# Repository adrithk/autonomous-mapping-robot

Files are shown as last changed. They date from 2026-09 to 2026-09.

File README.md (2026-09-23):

# Autonomous Indoor Mapping Robot

**ROS 2 Jazzy • SLAM Toolbox • Nav2 • ros2_control • Gazebo • ESP32**

A custom differential-drive robot that builds maps of indoor rooms and navigates to destinations selected in RViz. Built around a 3D-printed chassis, Raspberry Pi 5 and 360-degree LiDAR, it connects embedded wheel-speed control with a complete ROS 2 mapping and navigation stack.

Mapping uses keyboard teleoperation with **SLAM Toolbox**. Once the map is saved, **AMCL** localizes the robot and **Nav2** plans and drives the route to each selected goal.

## Demo

### Real-room mapping

| Physical robot | Room map in RViz |
|:---:|:---:|
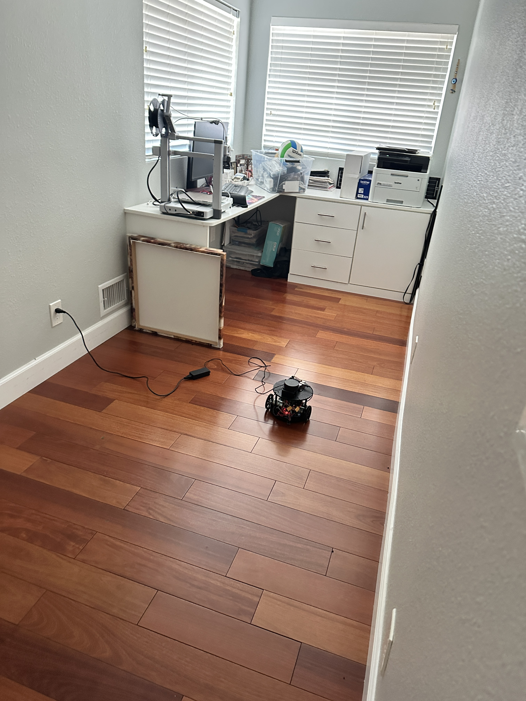
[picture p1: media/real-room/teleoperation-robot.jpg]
Custom robot with mounted LiDAR during room mapping
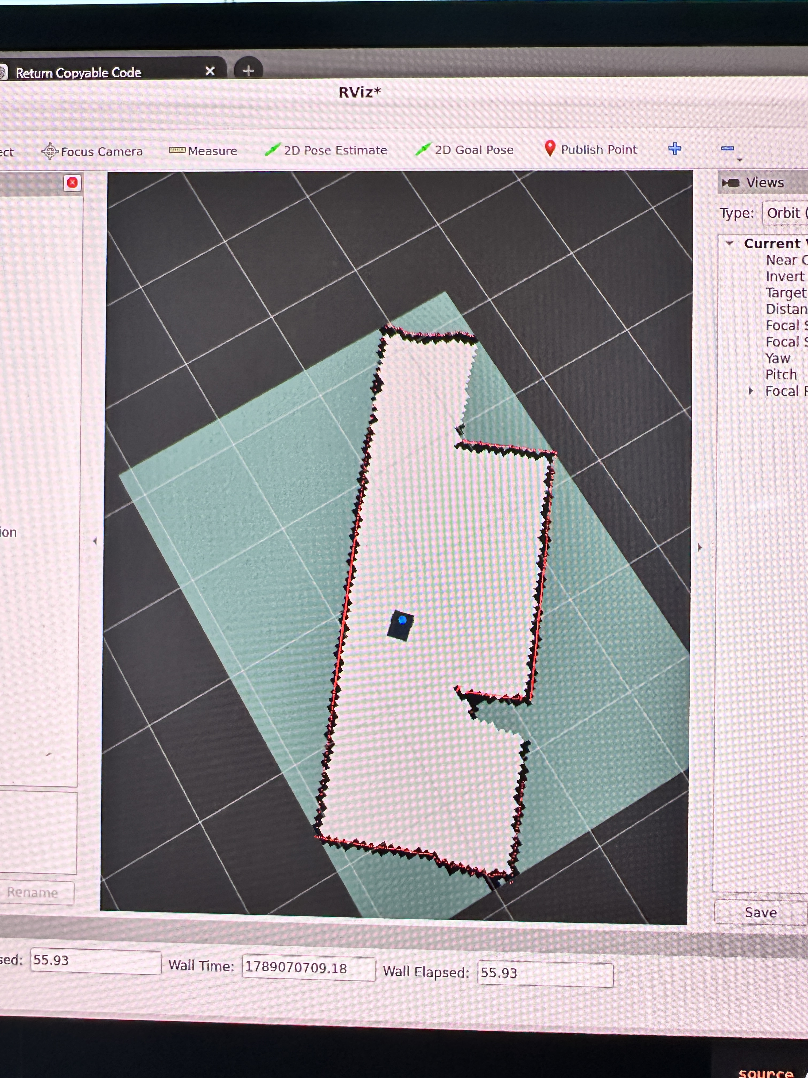
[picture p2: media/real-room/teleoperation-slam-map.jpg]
Room occupancy map and LiDAR returns displayed in RViz
|  |  |

The robot was driven through the room while LiDAR scans and encoder-based odometry supplied SLAM Toolbox with observations. The resulting occupancy map was saved for navigation.

### Nav2 navigation on the saved map

| Robot navigating · 49 s | RViz navigation view · 51 s |
|:---:|:---:|
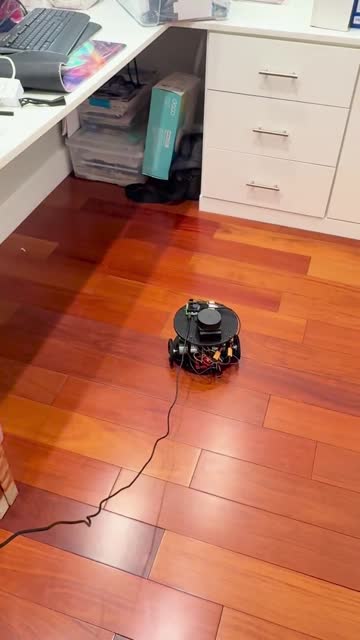
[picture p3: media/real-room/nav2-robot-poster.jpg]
Watch the physical navigation recording
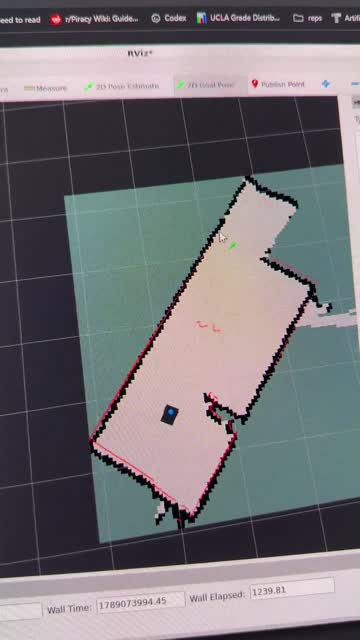
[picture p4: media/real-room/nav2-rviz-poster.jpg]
Watch the RViz navigation recording
|  |  |

Click a preview to watch or download the full-speed recording. On GitHub, use **View raw / Download** if playback is unavailable.

These initial demonstrations use operator-selected goals and tethered power. Setup, observations and measurement limits are documented in the [September 10 demonstration record](results/2026-09-10-real-room-mapping-navigation.md).

## Engineering highlights

- **Custom ROS hardware interface:** a C++ `ros2_control` plugin connects the standard differential-drive controller to the ESP32. The versioned serial protocol carries wheel commands and encoder feedback, with CRC checks, sequence tracking and an acknowledged stop at startup.
- **Embedded feedback control:** shared 50 Hz feed-forward/PI wheel controllers handle encoder sampling, command ramps and bounded motor outputs. An independent 250 ms watchdog stops commands that expire.
- **Mapping and navigation integration:** robot-specific Xacro, launch files, controller settings and TF connect wheel odometry and LiDAR to SLAM Toolbox, AMCL and Nav2.
- **Simulation and mechanical design:** Gazebo Harmonic provides a differential-drive model, simulated LiDAR and an obstacle room for integration testing. [STEP and STL files](hardware/cad/README.md) include the chassis, caster mount and LiDAR holder.

## How it works

The Raspberry Pi handles perception, localization and route planning. The ESP32 handles motor outputs and wheel-speed control, keeping command-loss handling independent of the ROS computer.

```text
Mapping:     LiDAR + wheel odometry → SLAM Toolbox → Saved map
Navigation:  Saved map + LiDAR + wheel odometry → AMCL localization

RViz goal → Nav2 → diff_drive_controller → Custom ros2_control plugin
                                                      │ USB serial
                                                      ▼
                                                ESP32 wheel PI → Motors
                                                      ▲
                                                   Encoders
```

### SLAM: turning laser scans into a room map

**Simultaneous Localization and Mapping (SLAM)** solves two connected problems: building a map of an unfamiliar space and estimating the robot's position within it. The RPLIDAR supplies a 360-degree slice of surrounding surfaces, while wheel encoders estimate how far the robot has moved between scans.

[SLAM Toolbox](https://github.com/SteveMacenski/slam_toolbox/tree/jazzy) uses **scan matching** to align overlapping laser observations and refine that motion estimate. It links successive robot poses into a **pose graph**. When a previously visited area is recognized, **loop closure** adds a constraint that lets the optimizer correct accumulated drift across the trajectory. The included [SLAM configuration](ros_ws/src/my_bot/config/slam.yaml) enables scan matching and loop closure with a Ceres solver.

The output is an **occupancy grid**: a spatial representation of free, occupied and unobserved areas. This project uses 5 cm map cells, displays the map and live laser returns in RViz, and exports the occupancy image with its scale and origin in a YAML file. Mapping is teleoperated; the saved map becomes the reference for autonomous navigation.

### Nav2: turning a destination into motion

For the physical saved-map workflow, **Adaptive Monte Carlo Localization (AMCL)** estimates the robot's position and heading. Its particle filter maintains candidate poses, predicts their movement from odometry, and weighs them against how well the current laser scan agrees with the map. This keeps navigation tied to observations of the room as the wheels turn. [AMCL documentation](https://docs.nav2.org/jazzy/configuration_and_development/configuration_guide/others/configuring_amcl/).

The operator then selects a destination and final heading in RViz. Nav2 separates finding a route from deciding how to drive the next part of it. The repository's [simulation navigation configuration](ros_ws/src/my_bot/config/nav2.yaml) makes that pipeline explicit:

- **Global planning:** NavFn uses Dijkstra search to find a route through known free space. Costmaps combine the map with laser observations; obstacle inflation assigns higher costs near walls and furniture to encourage clearance.
- **Local trajectory control:** DWB evaluates candidate forward and turning motions against obstacle costs, path alignment and progress toward the goal. The controller is configured to update at 20 Hz, repeatedly choosing the next velocity command as the robot moves.
- **Motion execution:** velocity smoothing limits acceleration, and a collision monitor checks laser observations before commands reach the drivetrain. The differential-drive controller converts body motion into wheel targets, which the ESP32 tracks using encoder feedback.

[NavFn](https://docs.nav2.org/jazzy/configuration_and_development/configuration_guide/planners_plugins/configuring_navfn/) and [DWB](https://docs.nav2.org/jazzy/configuration_and_development/configuration_guide/controller_plugins/dwb_controller/) provide the planning and control algorithms; this project's integration connects them to the custom robot. The physical recordings demonstrate saved-map navigation with AMCL, while the included simulation launch runs Nav2 alongside live SLAM. Exact physical-run planner settings and measured obstacle-response performance were not captured.

Mapping and saved-map localization run as separate modes. In simulation, Gazebo replaces the serial hardware interface while retaining the ROS controllers and robot model.

[System architecture](ARCHITECTURE.md) · [Serial protocol and interfaces](docs/interfaces.md) · [Hardware inventory](hardware/parts-list.md)

## Simulation

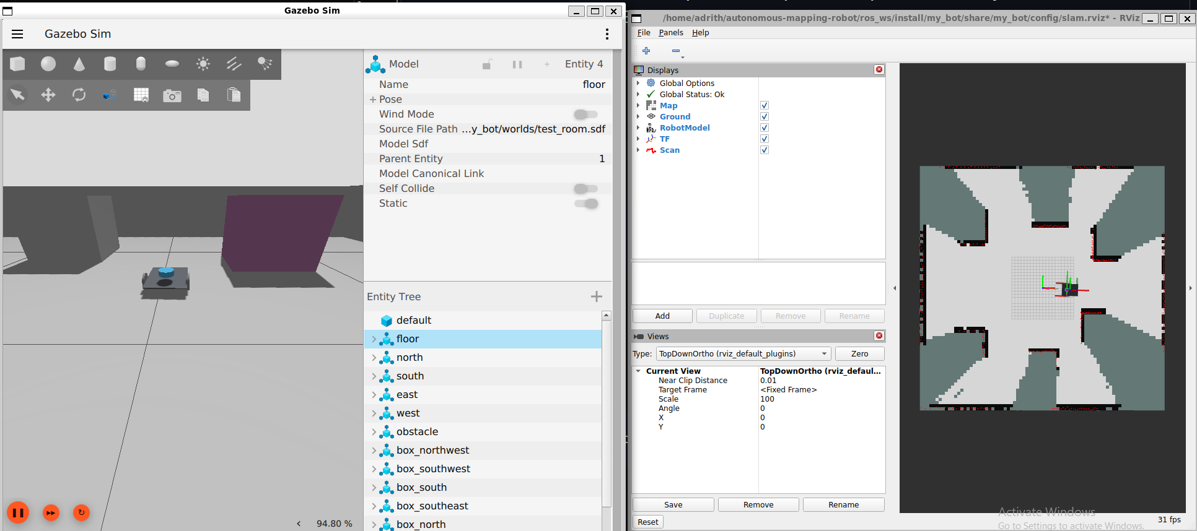
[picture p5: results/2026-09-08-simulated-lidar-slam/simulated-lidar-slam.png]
Gazebo obstacle room and the SLAM occupancy map in RViz


Gazebo models the robot in a room with six interior obstacles; RViz displays the map built from simulated laser scans. The simulation supports teleoperation, SLAM and Nav2 integration using estimated physical parameters. [Recorded simulation result](results/2026-09-08-simulated-lidar-slam.md).

To try it on Ubuntu 24.04 with ROS 2 Jazzy and Gazebo Harmonic, follow the [build instructions](ros_ws/src/my_bot/README.md#build), then launch:

```bash
ros2 launch my_bot slam_sim.launch.py
```

The [simulation guide](ros_ws/src/my_bot/SIMULATION.md) covers driving, map export and Nav2 goals. For the assembled robot, use the [hardware guide](ros_ws/src/my_bot/HARDWARE.md).

## Autonomous exploration

The robot's exploration implementation uses **frontier-based exploration** to choose where to go while building a map. SLAM Toolbox combines LiDAR scans and wheel odometry to update the map, and a custom ROS 2 exploration node identifies boundaries between known free space and unexplored areas.

The node selects nearby viewpoints with sufficient clearance, prioritizing larger frontiers and shorter travel distances. Nav2 checks whether a path is available and navigates to the selected destination. As new areas become visible, the map updates and the process repeats.

The exploration logic distinguishes between having no meaningful frontiers remaining and having frontiers that cannot currently be reached. It includes bounded retries, monitoring of sensor and navigation health, and automatic map saving after confirming the robot has stopped.

The included [exploration launch](ros_ws/src/my_bot/launch/explore_sim.launch.py) targets simulation. The repository's [recorded exploration verification](results/2026-09-09-exploration-offline.md) covers offline tests; integrated exploration and physical-run results remain to be documented.

## Verification

Automated checks cover wheel-control logic, protocol parsing, encoder rollover, host/firmware compatibility, emulated serial faults and ROS model/configuration consistency. Dated records also document raised-wheel tracking, simulated mapping and the physical room demonstration.

The demonstrations establish initial operation; map accuracy, navigation repeatability and physical stop timing have not been quantified. See [recorded results](results/README.md) and [verification instructions](docs/testing.md).

## Repository

| Location | Contents |
|---|---|
| [src/](src/) and [include/](include/) | ESP32 firmware and shared control/protocol logic |
| [ros_ws/src/my_bot/](ros_ws/src/my_bot/) | ROS hardware plugin, robot model, launch files, configuration and simulation |
| [hardware/](hardware/) | CAD files, component inventory and preliminary geometry |
| [test/](test/) and [ROS tests](ros_ws/src/my_bot/test/) | Firmware logic, serial transport and ROS integration checks |
| [results/](results/README.md) | Dated demonstrations and test evidence |

## Credits

Custom work includes the ESP32 firmware, serial transport and ROS hardware plugin, and robot-specific model, simulation and mapping integration. The robot description began with [Josh Newans’ my_bot template](https://github.com/joshnewans/my_bot), whose [Apache-2.0 license](ros_ws/src/my_bot/LICENSE.md) is retained. ROS 2, ros2_control, Gazebo, SLAM Toolbox and Nav2 provide the underlying robotics frameworks.

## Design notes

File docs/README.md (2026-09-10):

# Documentation

Start with the [project README](../README.md) for the robot, demonstrations and engineering highlights.

| Guide | Contents |
|---|---|
| [Build and robot model](../ros_ws/src/my_bot/README.md) | ROS workspace setup, firmware builds and geometry |
| [Simulation](../ros_ws/src/my_bot/SIMULATION.md) | Teleoperation, SLAM, map export and Nav2 goals |
| [Hardware](../ros_ws/src/my_bot/HARDWARE.md) | Pi/ESP32 bringup and physical checks |
| [Architecture](../ARCHITECTURE.md) | Component ownership and data flow |
| [Interfaces](interfaces.md) | Serial protocol, units, frames and GPIOs |
| [Testing](testing.md) | Automated checks and physical verification |
| [Hardware inventory](../hardware/parts-list.md) | Components, CAD and preliminary measurements |
| [Results](../results/README.md) | Dated evidence and demonstration limits |

[Technical decisions](decisions/README.md) and [execution plans](plans/) preserve
engineering rationale and development history. The [capability summary](../ROADMAP.md)
reflects the recorded demonstrations.

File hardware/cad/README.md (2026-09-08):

# Robot CAD

CAD files supplied by the project owner on September 7, 2026. Original filenames
and file contents are preserved.

| File | Format |
|---|---|
| [Robot CAD](autonomous_SLAM_robot_cad.step) | STEP |
| [Chassis](chassis.stl) | STL |
| [Caster mount](caster_mount.stl) | STL |
| [LiDAR holder](Lidar_Holder.stl) | STL |
| [Pillar](PILLAR.stl) | STL |

Assembly image, print settings, material, fasteners, CAD revision and confirmation
of the revision used on the physical robot: **TBD**. The files have been copied
and checked for byte-for-byte integrity; printability, dimensions and assembled
fit have not been validated in this upload.

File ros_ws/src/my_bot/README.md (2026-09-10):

# my_bot — ROS 2 robot integration

ROS 2 Jazzy package for the indoor mapping robot: a custom ESP32 hardware plugin,
differential-drive control, robot description, Gazebo simulation and SLAM/Nav2 integration.
See the [project README](../../../README.md) for physical demonstrations.
The package is also mirrored in [adrithk/my_bot](https://github.com/adrithk/my_bot);
the commands below use the consolidated repository, which includes the firmware and tools.

## Build

Requires Ubuntu 24.04, ROS 2 Jazzy, `ros-dev-tools` and an initialized `rosdep`.
Simulation also requires Gazebo Harmonic and a working graphics environment.
The package declares its ROS and Gazebo dependencies for `rosdep`.

```bash
source /opt/ros/jazzy/setup.bash
git clone https://github.com/adrithk/autonomous-mapping-robot.git
cd autonomous-mapping-robot/ros_ws
rosdep update
rosdep install --from-paths src --ignore-src -r -y --rosdistro jazzy
colcon build --packages-select my_bot --symlink-install
source install/setup.bash
colcon test --packages-select my_bot
colcon test-result --verbose
```

For an existing checkout, run the dependency/build/test steps from `ros_ws`.
In each new terminal, source ROS and this workspace's `install/setup.bash`.

| Mode | Command / guide |
|---|---|
| Model preview | `ros2 launch my_bot display.launch.py` |
| Gazebo driving | `ros2 launch my_bot bringup.launch.py` |
| Simulated mapping | `ros2 launch my_bot slam_sim.launch.py` |
| Simulated navigation with live SLAM | `ros2 launch my_bot nav_sim.launch.py` |
| Pi + ESP32 | [Hardware guide](HARDWARE.md) — explicit serial device required |

Run one control mode at a time. The model preview uses synthetic joint states;
close it before simulation or hardware operation. The [simulation guide](SIMULATION.md)
covers teleoperation, map saving and navigation.

### ESP32 firmware

Install PlatformIO and build from the repository root. Select the entry point explicitly:

```bash
pio run -e keyboard
pio run -e ros_serial
```

`keyboard` provides direct serial-key control; `ros_serial` speaks the ROS wheel
protocol. Both share the controller implementation. Add `-t upload` to the chosen
build command when flashing an attached ESP32.

## Dimensions and frames

All geometry is in `description/dimensions.xacro`, in metres.

| Input | Value | Evidence |
|---|---:|---|
| Wheel radius | 0.040 | Builder-reported |
| Wheel center separation | 0.205 | Builder confirmed after motor relocation |
| Outside tire width | 0.215 | Builder-reported |
| Individual tire width | 0.010 | Inferred assuming identical tires |
| Axle to front / rear | 0.180 / 0.080 | Builder-approved; total 0.260 |
| Chassis underside clearance | 0.040 | Builder-authorized assumption |
| Plate thickness | 0.005 | Visual approximation |
| Caster radius | 0.020 | Visual approximation; not measured |

`base_link` is on the ground below the drive-axle midpoint. +X points toward
the front caster, +Y left, +Z up. Both wheel joints rotate about +Y; positive
rotation represents forward rolling. Wheel centers sit 0.040 m above ground.
The chassis is a thin rectangular approximation of the whole envelope, including
the front extension, not an exact outline of the circular plate in the photos.
The caster is a fixed sphere placeholder, not a swivel mechanism model.

For Nav2, the provisional rectangular footprint relative to base_link
is `[[0.18, 0.1075], [0.18, -0.1075], [-0.08, -0.1075], [-0.08, 0.1075]]`.
Recheck wires, final payload and caster sweep before navigating. URDF collision
geometry alone does not configure Nav2's footprint.

LiDAR is enabled with a builder-authorized provisional mount: x=0, y=0,
z=0.10 m, yaw=0 (level, facing forward). "6 cm above the wheels" is interpreted
as 6 cm above the axle centers, which are 4 cm above the floor. These are
assumptions, not measurements. The blue LiDAR cylinder is a visual placeholder
(radius 3.5 cm, height 2.5 cm), not measured sensor geometry. Laser x/y are measured from the axle
midpoint, z from the floor to the scan plane, yaw in radians about +Z. The launch
requires positive z when enabling LiDAR. Its driver frame must match `laser`.
No IMU is modeled. Estimated inertias and mass distribution are provided for
simulation only; they do not establish real physical behavior.

## Model snapshot

`description/robot.urdf` is a generated snapshot for generic URDF viewers.
After changing dimensions, regenerate it from the package directory:

```bash
xacro description/robot.urdf.xacro -o description/robot.urdf
```

Geometry is preliminary; simulation masses, inertias and contact properties are
estimates. [Hardware inventory](../../../hardware/parts-list.md) records their provenance.

## Verification and attribution

[Testing](../../../docs/testing.md) describes the automated checks and remaining
physical measurements. [Dated results](../../../results/README.md) include initial
simulation and physical mapping/navigation demonstrations.

Adapted from [Josh Newans’ my_bot template](https://github.com/joshnewans/my_bot)
under [Apache-2.0](LICENSE.md). Import provenance is in the [workspace README](../../README.md).

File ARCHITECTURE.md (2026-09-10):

# System architecture

Updated September 10, 2026. The repository contains two ESP32 entry points and one
ROS 2 Jazzy package, `my_bot`. The documented workflow is teleoperated room
mapping followed by autonomous path planning and navigation on the saved map.

## Ownership and implementation

| Component | Owner / source | Implementation and validation |
|---|---|---|
| Encoder sampling, PWM, feed-forward/PI | ESP32 `src/robot_drive.cpp` | Shared 50 Hz controller; earlier raised-wheel tracking recorded |
| Keyboard command entry point | ESP32 `src/main.cpp` | Timed movement, encoder reporting, stop commands |
| Serial command entry point | ESP32 `src/main_ros.cpp` | v2 CRC/sequence framing, 20 Hz telemetry, 250 ms watchdog; initial physical operation reported |
| Serial hardware plugin | `ros_ws/src/my_bot/src/esp32_system.cpp` and `serial_transport.cpp` | Implemented; offline transport tests; ROS plugin loading and initial physical operation reported; fault/stop acceptance pending |
| Wheel commands and odometry | Standard `diff_drive_controller` | Configured for simulation and hardware; encoder feedback supplies odometry |
| Robot description and transforms | `my_bot/description/`, robot_state_publisher | Xacro and preliminary geometry; offline checks |
| Simulation | Gazebo Harmonic and `gz_ros2_control` | Initial WSL driving/scans demonstrated |
| Mapping | SLAM Toolbox; simulation wrapper `slam_sim.launch.py` and upstream physical launch | Simulation and initial physical teleoperated mapping; manual map save reported |
| Physical LiDAR driver | Upstream `rplidar_ros` on the Pi | A1M8 via GPIO UART; scan publication and physical mapping demonstrated |
| Nav2 click-to-go navigation | `my_bot/launch/nav_sim.launch.py`; Nav2/AMCL saved-map workflow | Simulation implementation plus initial physical saved-map navigation demonstration |

## Control and data flow

In hardware mode, stamped body velocity commands reach `diff_drive_controller`.
It converts them into left/right rad/s commands for `my_bot/Esp32System`, which owns
USB serial at 115200 baud. The ESP32 converts rad/s into local counts/s targets and
returns raw encoder counts and speed. The host converts feedback into radians and
rad/s. The preliminary encoder calibration is 4185 counts/revolution per wheel.

The host requires fresh telemetry and an acknowledged stop at startup. Telemetry
or ACK stalls beyond 200 ms, new firmware faults, time regression, or I/O failures
fault control and attempt a stop. Reconnection is deliberate; previous commands
are not automatically replayed. The ESP32 independently enforces its 250 ms lease.
These are source behaviors with offline test coverage; the demonstration record does not measure their physical response times.

Simulation uses Gazebo wheel interfaces instead of the serial plugin. The default
ROS bringup selects simulation; `mode:=hardware` requires an explicit serial device.
Simulation uses `/clock`; hardware uses wall time. The two backends are exclusive.

## Frames and configuration

The configured chain is `map -> odom -> base_link -> laser`. SLAM Toolbox owns
`map -> odom` when the SLAM launch runs; `diff_drive_controller` owns `odom -> base_link`;
AMCL instead owns `map -> odom` in saved-map localization mode; do not run both
localization sources together. `robot_state_publisher` owns robot link transforms. No IMU is modeled, and
`robot_localization` is deferred until another useful odometry source exists.

- `platformio.ini`: mutually exclusive firmware source filters. Use explicit environments.
- `src/robot_drive.cpp`: motor/encoder pins, controller gains, limits and polarity.
- `include/ros_wheel_units.h`: ROS firmware wheel-unit conversion.
- `ros_ws/src/my_bot/description/dimensions.xacro`: preliminary robot geometry.
- `ros_ws/src/my_bot/config/`: controller geometry/limits, clocks, bridge, SLAM and RViz.
- `ros_ws/src/my_bot/description/simulation_parameters.xacro`: estimated simulation physics.

Geometry is provisional: wheel radius 0.040 m, center separation 0.205 m and LiDAR
scan plane 0.10 m above the floor. Hardware inventory and measurement provenance
live in [hardware/parts-list.md](hardware/parts-list.md); simulation estimates are
not physical calibration. Exact units, topics, GPIOs and transport framing are in
[docs/interfaces.md](docs/interfaces.md).

## Hardware and acceptance

The reported platform uses an ESP32, two encoder gearmotors, two BTS7960 modules,
a level shifter, battery, wheels, and printed chassis. The Pi 5 and RPLIDAR A1M8
are present in the [September 10 physical demonstration](results/2026-09-10-real-room-mapping-navigation.md),
which uses tethered power. The demonstration record distinguishes observed operation from measured calibration.
The earlier Cytron driver is retired. The supplied demonstration does not include power-isolation or repeated stop measurements.

See [testing](docs/testing.md), [dated results](results/README.md), and the
[capability summary](ROADMAP.md) for the distinction between source, automated checks,
observed operation, and integrated acceptance.

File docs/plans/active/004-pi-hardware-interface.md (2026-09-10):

# Pi hardware interface and selectable simulation

Date: 2026-09-07. Status: implementation/offline checks complete; runtime acceptance pending.

## Bounded scope

Implement my_bot/Esp32System in the sibling ROS package, speaking the existing
ESP32 v2 protocol. Default to Gazebo; real bringup explicitly selects a serial port.
Check plugin registration/build dependencies, Xacro, YAML clocks/limits, Python launch
syntax, unit conversion, USB framing, sequence synchronization and fault stopping.
Keep ESP32 firmware unchanged. SLAM/Nav2/LiDAR hardware driver are follow-up tasks.

## Implemented

- Standard Jazzy SystemInterface with two velocity command and position/velocity state interfaces.
- POSIX 115200 serial connection with a fresh stop-ACK handshake; preliminary4185
  counts/revolution feedback conversion, signed count wraparound, 200 ms telemetry
  and acknowledgement health checks, stop on fault and deliberate reconnect only.
- Mutually exclusive hardware/simulation Xacro and launch; simulation default.
- Separate clock settings with common geometry and conservative velocity limits.
- WSL source bundle and setup/teleop instructions in sibling WSL_SETUP.md.

## Offline verification (2026-09-07)

Six model tests pass for geometry, inertias/frames, sensor wiring, backend isolation,
YAML clocks/limits, XML/Python syntax and plugin declarations. Native C++17 transport
and pseudo-terminal tests pass with clang++ -Wall -Wextra -Werror, covering CRC,
field bounds, handshake, ACK wrap, reconnect, malformed/stale feedback, stalled ACK,
reboot, new status faults and host stalls. A compatibility harness compiled against
this repository's actual ros_serial_protocol.h accepts host C/X frames and decodes
firmware S frames. No ESP32 source edits were required in this task.

## Remaining acceptance

- On Ubuntu 24.04: colcon build/test/test-result; load plugin via controller_manager.
- On WSL2: launch Gazebo, confirm active controllers, wheel motion, odometry and scans.
- On Pi: upload ESP32 ROS build; raised-wheel direction/stop/watchdog/disconnect trials
  and dated results before ground driving. Final geometry/calibration remains provisional.

No ROS/Gazebo installation or Pi was available here. Do not mark this plan complete
until runtime checks are recorded. Existing transport plan 003 physical criteria
remain open.

2026-09-07 user evidence update: [initial simulation implementation](../../../results/2026-09-07-initial-simulation.md)
records working WSL Gazebo/WASD and 10 Hz simulated LiDAR display, with photo.
Initial simulation smoke testing is now observed; physical and SLAM acceptance
remain pending. Exact PC revision and repeatable startup have not been recorded.

## Repository consolidation — 2026-09-07

The full ROS package is now in `ros_ws/src/my_bot` in this repository. Earlier
sibling-package references are historical. Source behavior and pending physical
acceptance are unchanged. See [current status](../../../ROADMAP.md).

## September 9: latched ROS teleoperation

Bounded follow-up: user requested press-once WASD after hold-to-run only twitched
over SSH while a timed 0.10 m/s command reportedly moved steadily. Add opt-in
`latched:=true` to the existing Python teleop. Default hold-to-run, controller and
ESP32 watchdogs, firmware and speed limits remain unchanged. X/Space/unknown keys
stop; a direction key replaces the current direction. Releasing a key in latched
mode does not stop. This does not detect a network outage while the remote process
remains alive and publishing; keep motor power removal accessible during testing.

Implemented and verified: five offline teleop tests pass, including default expiry,
latched persistence, direction changes, stop and restart. Local colcon is unavailable;
Jazzy/SSH latched-mode operation and physical X/Space stopping remain pending.
See [initial Pi observations](../../../results/2026-09-09-pi-teleop.md).

## September 9: one-revolution bench check

User requested a one-wheel-revolution accuracy check after timed motion worked.
Added standalone `tools/wheel_revolution_test.py`: targets +2*pi relative position
on both raised wheels using /joint_states, slows near the endpoint, commands body
TwistStamped through the existing controller, then sends zero and checks stationary
feedback. Uses geometry from installed controllers_hardware.yaml. Known geometry
must match the running controller. No firmware or gains/limits changes.

Guards: other detected command publishers, invalid/stale feedback, initially moving
wheels, reversed counts, excessive overshoot, 20-second motion limit and 2-second
stop-confirmation limit. Requires manual tyre marks: encoder-estimated travel alone
cannot validate the same counts/revolution calibration that defines its endpoint.
Seven offline target-selection checks passed (start, independent completion, near-
endpoint slowdown, tolerance, negative direction, overshoot and nonfinite values).
ROS runtime/physical accuracy and stop timing remain untested for this script.

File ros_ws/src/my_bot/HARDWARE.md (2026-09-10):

# Real ESP32 control (opt-in)

Default: `ros2 launch my_bot bringup.launch.py` starts **simulation**. The hardware
library is compiled but is never loaded by the simulation model. Stop one launch
before starting the other; the mode switch is a restart, not a live transfer.
Do not run preview joint publishers alongside either control mode.

## Pi first connection

1. Install Ubuntu 24.04 arm64 and ROS 2 Jazzy, then follow the [package build steps](README.md#build). This is a ROS computer package, not ESP32 firmware.
2. Upload the **ros_serial version 2** build from autonomous-mapping-robot to the
   ESP32. Select `pio run -e ros_serial -t upload` explicitly; the keyboard firmware does not speak this protocol.
3. Connect ESP32 to the Pi with a USB **data** cable. Close any serial monitor.
4. Add your Pi user to the serial group, then log out/in:
   `sudo usermod -aG dialout "$USER"`. Locate the ESP32 with `ls -l /dev/serial/by-id/`.
   Identify it by unplugging/reconnecting the ESP32, especially once LiDAR is attached.
5. Raise both drive wheels for initial testing and have motor-power removal within
   reach. Confirm the newly mounted wheels still move toward the front caster
   for positive commands. Calibration is provisional: 4185 counts/revolution each.
6. Enable hardware explicitly, replacing the example device path:

```bash
source /opt/ros/jazzy/setup.bash
source ~/autonomous-mapping-robot/ros_ws/install/setup.bash
ros2 launch my_bot bringup.launch.py mode:=hardware rviz:=false \
  serial_device:=/dev/serial/by-id/YOUR_ESP32
```

In another Pi terminal (SSH is fine):

```bash
source /opt/ros/jazzy/setup.bash
source ~/autonomous-mapping-robot/ros_ws/install/setup.bash
ros2 run my_bot teleop_wasd --ros-args \
  -p use_sim_time:=false -p frame_id:=base_link \
  -p speed:=0.05 -p turn:=0.3 -r cmd_vel:=/diff_drive_controller/cmd_vel
```

`w` forward, `s` reverse, `a` left, `d` right; space or `x` stops. Hold a direction
key for repeats; the teleop sends zero after 0.2 s without another key event. The initial
OS key-repeat delay can cause a pause. Ctrl-C ends teleoperation. The controller also has an independent 0.25 s message timeout. This is ordinary stopping, not an emergency stop.

For press-once operation, add `-p latched:=true` to the teleop command. W/A/S/D
then persist until X/Space (or another direction). Releasing a key does not stop;
controller/ESP32 watchdogs still require loss of messages, not operator inactivity.
Keep power removal accessible and verify stopping with raised wheels.

## What runs where

Pi: TwistStamped body velocity -> diff_drive_controller -> wheel rad/s ->
`my_bot/Esp32System` -> CRC-framed USB commands. ESP32: rad/s -> counts/s ->
existing local PID. Raw encoder telemetry returns through the plugin as wheel
position (radians) and velocity (rad/s); controller publishes odometry/TF.

- Wire contract: 115200, 8N1, protocol 2, C/X/S messages defined in the [interface specification](../../../docs/interfaces.md). No third-party Arduino text protocol works here.
- Joint order/names: left_wheel_joint, right_wheel_joint. Velocity command and
  position/velocity state interfaces on both. No effort command or IMU.
- `description/hardware.xacro` owns feedback calibration; keep it synchronized
  with firmware `include/ros_wheel_units.h` if counts/revolution changes.
- Hardware YAML uses real time; simulation YAML uses `/clock`. Geometry matches; speed
  limits differ: simulation permits faster linear motion. Physical limits: 0.15 m/s and 0.75 rad/s;
  the plugin additionally scales wheel pairs to at most 6 rad/s, preserving curvature.
- Serial port is explicitly selected, raw, nonblocking and advisory-locked. Close
  other serial programs (programs that ignore advisory locks can still interfere).
- Activation waits up to 4 seconds for v2 telemetry, synchronizes to its ACK,
  sends a new stop and requires a fresh stop ACK with zero PWM before enabling commands.
- Runtime read/write work is bounded. Feedback or command ACK stalls over 200 ms,
  ESP32 clock regression/reboot, I/O failure or a newly latched firmware fault
  fail control and close the connection. Invalid CRC does not refresh freshness.
- Previously latched status bits are logged at activation; firmware cannot clear
  them without reboot. A repeat of an already-latched bit cannot be distinguished.
- Disconnect/deactivate/error/destruction attempt a stop. Delivery is best effort;
  the ESP32's independent 250 ms watchdog remains required. No automatic reconnect
  or replay of the last target: stop bringup, fix the issue, and relaunch deliberately.
- Counts are unwrapped using signed 32-bit modular deltas. ROS position starts at
  zero for each process; reboot causes a fault rather than an odometry jump.

## Before ground driving / SLAM

Verify zero PWM at startup, wheel directions and feedback signs, zero commands,
explicit stop, host termination, bad frames, and unplug/reconnect while moving.
Record three watchdog/disconnect trials in the [results directory](../../../results/README.md).
Then measure travel/turn accuracy under the final payload and correct geometry.

## Mapping and navigation

Hardware bringup starts drivetrain control and robot transforms; it does not start
a LiDAR driver, SLAM or Nav2. The [September 10 demonstration](../../../results/2026-09-10-real-room-mapping-navigation.md)
used upstream `rplidar_ros` with an A1M8 on GPIO UART (`/dev/ttyAMA0`, 115200 baud),
publishing `/scan` in frame `laser`.

For physical mapping, SLAM Toolbox combines scans and wheel odometry while the
operator drives, then saves an occupancy map. For navigation, stop teleop and SLAM,
load that map with map server and AMCL, initialize the pose in RViz, and use Nav2
to reach selected goals. Physical nodes use wall time. Confirm the mounted laser
transform and loaded wheel geometry before reproducing the setup.

The demonstration's exact running revisions and complete launch configuration
were not captured. This repository's `nav_sim.launch.py` is for simulation;
it is not a packaged reproduction of the physical saved-map launch.

## Verification limits

Native tests exercise the transport with an emulated ESP32, including handshake,
CRC, stale feedback and fault cases. Offline checks cover model/configuration and
launch contracts. Initial physical plugin operation, mapping and navigation are
recorded; revision-pinned ROS build/test results, calibrated odometry, repeated
startup and physical fault/stop timing remain open measurements.

## Visual one-revolution check

Keep the hardware launch running, stop all WASD/Nav2 publishers, and mark both
tyres against a fixed reference with both wheels raised. From the consolidated `autonomous-mapping-robot` repository root
in a sourced Pi shell using the same ROS domain as the launch, run:

```bash
python3 tools/wheel_revolution_test.py
```

The standalone script aims for one forward revolution of each wheel, slows toward
the encoder endpoint, then commands zero and checks stationary feedback. It prints
final encoder-estimated revolutions. Compare actual tyre marks independently; ROS
reporting one revolution does not establish correct encoder calibration. There is
no guaranteed exact stop angle. Geometry comes from installed hardware controller
YAML, which must match the running controller. Timeout/feedback checks do not replace
independent motor-power removal. Target ROS/physical testing remains pending.

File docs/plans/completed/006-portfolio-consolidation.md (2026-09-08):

# Portfolio documentation and ROS consolidation

Date: 2026-09-07. Status: complete.

## Scope

Copy every tracked file from the my_bot repository into ros_ws/src/my_bot,
preserving package identity, source behavior, license, original evidence and plans.
Polish the public documentation, add clearly labeled TBD media/results slots,
resolve stale current-state statements, obtain an independent recruiting review,
verify the copy and available checks, then commit and push the presentation work.
Existing physical acceptance plans remain active. No new robotics functionality.

## Acceptance

- All 47 tracked source-package files retained; non-document files byte-identical.
- README, architecture, setup and status agree with the consolidated repository.
- Demo, room photos/maps, measurements and reproducibility have upload instructions.
- Independent recruiting review incorporated and links/available tests checked.
- Presentation changes committed and pushed; existing platformio.ini edit preserved separately.

## Progress

- Source inspected at my_bot commit 97ebb4b274198aeb2aaafc89acfd5a8dfd1bc3bb.
- Copied tracked files; excluded nested .git and generated build outputs.
- Independent recruiting review requested.

## Review and verification

Independent recruiting/engineering review recommended a concise showcase README,
explicit contribution attribution, minimal source movement, preserved provenance,
consistent current-state documentation and practical media/evidence slots. Applied.

- All 47 tracked package files retained from the recorded import commit.
- Every non-Markdown package file matches that commit byte for byte.
- Eight model/configuration tests and three teleoperation tests passed.
- Native controller, protocol, pseudo-terminal transport and firmware conformance tests passed.
- Both PlatformIO environments built successfully on macOS.
- Local Markdown links resolve; git diff --check passes.
- colcon build/test/test-result unavailable: this Mac has no ROS installation.
- No physical validation or SLAM runtime acceptance is claimed.

A concurrent code audit completed before this task committed: firmware rollover
fixes are separately committed as 0119611, and the final ROS import matches
my_bot 10c2beb58b34006a5841c2e3cba88462cb117117 (47 tracked files). Its new
ROS-dependent hardware_plugin_test is retained but cannot run on this Mac.
The final non-document files were compared byte for byte with that revision.
The user's existing platformio.ini edit remains local and uncommitted.

The initial recruiting review and follow-up review were applied, including corrected
clone location, rosdep initialization, Xacro working directory and simulation status.

## Delivery

Committed as 79e9217 and 9b260fb; pushed successfully to
`https://github.com/adrithk/autonomous-mapping-robot` branch `main` on 2026-09-07.
GitHub verified the signed-in owner/admin and public visibility for both repositories.
Presentation acceptance is complete. Physical and autonomous-mapping plans remain active.

## Showcase revision — 2026-09-07

At the owner's request, replaced the README media table with “Demo: To Be Uploaded”
below engineering highlights, removed public setup tutorials, and expanded the
ROS 2, SLAM Toolbox and Nav2 final-design description. Nav2 integration remains
explicitly pending in the implementation status. Showcase scope is one or two rooms
and one video; removed the unused third-room placeholder. Existing technical guides
and all source functionality are preserved. Markdown links and diff checks passed.

## CAD upload — 2026-09-07

Added the owner-supplied robot STEP and chassis, caster mount, LiDAR holder and
pillar STL files to `hardware/cad/`, preserving original filenames and bytes.
Updated the CAD index and completion checklist. Source/destination SHA-256
comparisons passed for all five files; no geometry or physical fit validation
is claimed. Firmware and ROS functionality are unchanged.

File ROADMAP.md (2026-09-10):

# Demonstrated capabilities

Updated September 10, 2026. This page summarizes the implemented system and recorded demonstrations.

| Capability | Implementation and evidence |
|---|---|
| Motor control | ESP32 encoder-feedback wheel-speed control with feed-forward/PI, command ramps and watchdogs |
| ROS integration | Pi-side ros2_control serial plugin, differential-drive controller, wheel odometry and robot TF |
| Physical LiDAR | RPLIDAR A1M8 connected to the Pi through GPIO UART; scan publication demonstrated |
| Room mapping | Keyboard teleoperation with SLAM Toolbox, live RViz visualization and manual map saving |
| Autonomous path planning | Nav2 plans and drives to destinations selected in RViz, using AMCL localization on the saved map |
| Simulation | Gazebo differential-drive model, simulated LiDAR, SLAM and Nav2 integration |

The [physical demonstration record](results/2026-09-10-real-room-mapping-navigation.md)
contains the room photographs, navigation recordings and their evidence limits.
The [initial simulated SLAM result](results/2026-09-08-simulated-lidar-slam.md)
documents the earlier simulation demonstration. Recorded movement and map output
are distinct from quantitative accuracy or reliability measurements.

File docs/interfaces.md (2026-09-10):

# Subsystem interfaces

Unknown values are deliberately marked `TBD`. Update this file in the same change as any interface modification.

## Keyboard serial command interface

**Owner:** `src/main.cpp` on the ESP32  
**Transport:** Arduino `Serial` over the board's serial connection  
**Configured rate:** 115200 baud  
**Framing:** one byte read at a time; no packet framing, checksum, sequence number, acknowledgement, or version  
**Update behavior:** polled continuously in `loop()`; `w`/`s` ramp up over 300 ms, ramp down during the final 300 ms, and stop after 5000 ms. `a`/`d` ramp up over 100 ms, ramp down during the final 100 ms, and stop after 1000 ms. Explicit, invalid-input, and timeout stops remain immediate.
**Units:** keyboard commands select fixed signed encoder-count-per-second targets; counts/revolution is preliminary

| Input byte | Left target | Right target | Intended motion |
|---|---|---|---|
| `w` | +3000 counts/s | +3000 counts/s | Forward for up to 5 seconds |
| `s` | -3000 counts/s | -3000 counts/s | Reverse for up to 5 seconds |
| `a` | -1800 counts/s | +1800 counts/s | Left turn for up to 1 second |
| `d` | +1800 counts/s | -1800 counts/s | Right turn for up to 1 second |
| `x` | 0 counts/s | 0 counts/s | Stop and reset both controllers |
| `e` | unchanged | unchanged | Print encoder counts |
| carriage return / newline | unchanged | unchanged | Ignored; does not renew the motion lease |
| any other byte | both PWM outputs 0 | both PWM outputs 0 | Stop |

The firmware prints startup, timeout, and unknown-command messages. While a motion
command is active, it prints each wheel's requested command, ramped target counts/s,
measured counts/s, controller PWM, and raw count every 200 ms. The `e` command prints
only `left_count=<count> right_count=<count>` immediately, without resetting either
count. It does not echo every received byte.

### Known limitations

- Controller calculations have automated checks and the firmware builds. Raised-wheel forward/reverse tracking passed at +/-3000 counts/s on 2026-09-04; ground-load performance remains unverified.
- There is no variable-speed command, driver-fault input, or framed/acknowledged transport.
- ROS uses a preliminary counts/revolution estimate; conversion accuracy remains unverified.
- Initial gains and left/right electrical polarity require controlled hardware validation.
- This interface is a bring-up control, not a suitable final ROS transport contract.

## Current motor driver output interface

**Owner:** ESP32 firmware  
**PWM:** 20 kHz, 8-bit resolution, Arduino LEDC API; controller output limited to 200
**Motor drivers:** two reported HiLetgo BTS7960 single-channel modules, one per motor. Their basic movement has been demonstrated, but exact board revision, electrical limits, thermal behavior, and safe-state behavior remain unverified. The former Cytron MDD10A is reported damaged and must not be used.
**Reported motors:** two expected 12 V metal DC gearmotors with encoders, 131:1, 83 RPM, 45 kg.cm; exact manufacturer/model is unconfirmed  
**Electrical levels, enable polarity, braking/coasting behavior, and motor rated/stall current:** `TBD`

| Channel | BTS7960 GPIOs | Verification status |
|---|---|---|
| Shared enable | GPIO 27 to all four `R_EN`/`L_EN` pins | Reported connected; external 10 kΩ pull-down intended; electrical safe-state test pending |
| Left | GPIO 25 `RPWM` + GPIO 26 `LPWM` | Motion and PID telemetry observed; exact electrical verification pending |
| Right | GPIO 32 `RPWM` + GPIO 33 `LPWM` | Motion and PID telemetry observed; exact electrical verification pending |

## Current encoder input interface

**Owner:** ESP32 firmware
**Electrical path:** encoder A/B signals -> four-channel 5 V-to-3.3 V level shifter -> ESP32 inputs
**Acquisition:** interrupt on each A channel; B is read to infer direction. Count differences are converted to counts/s at a nominal 50 Hz using actual elapsed time. ROS conversion uses the preliminary 4185 counts/revolution estimate below; measured calibration remains pending.

**Controller:** one controller per wheel using initial gains `Kp=0.020`, `Ki=0.010`, `Kd=0.000`, and feed-forward `0.048 PWM/(count/s)`. Integral magnitude is limited to 4000 count-seconds and output to PWM 200. Straight targets use a 10000 counts/s² slew limit for a 300 ms ramp to 3000 counts/s; turn targets use an 18000 counts/s² limit for a 100 ms ramp to 1800 counts/s. These values are provisional pending physical tuning.

| Wheel | A input | B input |
|---|---:|---:|
| Left | GPIO 34 | GPIO 35 |
| Right | GPIO 36 (`VP`) | GPIO 39 (`VN`) |

Both encoder count signs have been observed in forward and reverse. Signal voltage, count resolution, missed-count behavior, and the exact level-shifter electrical performance remain unverified. GPIO 34-39 have no internal pull resistors; the external level shifter must provide suitable pull-ups.

Pin assignments, gains, limits, and polarity are shared by both firmware entry points in `src/robot_drive.cpp`. The reported four-channel level shifter is used for encoder signals, not motor-driver control inputs; its electrical behavior still requires measurement.

## ROS-ready USB serial protocol

**Implementation:** `src/main_ros.cpp` and `include/ros_serial_protocol.h`
**Build environment:** `ros_serial`
**Transport:** USB serial at 115200 baud, ASCII, newline-delimited
**Protocol version:** 2
**Command rate:** intended 50 Hz from the Pi
**ESP32 watchdog:** 250 ms from the last valid, newer command frame
**Telemetry rate:** 20 Hz
**Wire units:** commands in wheel rad/s; feedback remains encoder counts and counts/s.
The ESP32 converts commands; the Pi plugin converts feedback to radians and rad/s.

Every payload is followed by `*HHHH\n`, where `HHHH` is four uppercase hexadecimal
digits containing CRC-16/CCITT-FALSE over every ASCII byte before `*` (polynomial
`0x1021`, initial value `0xFFFF`, no reflection, no final XOR). Carriage returns are
ignored. Frames longer than the fixed 128-byte receive buffer are rejected.
The buffer reserves one byte for the string terminator. The first byte exceeding
127 buffered bytes immediately stops both wheel controllers and latches the overflow
status, without waiting for a newline or watchdog expiry. Remaining input in that
frame is discarded through the next newline; a subsequent valid, newer command may
resume motion.

| Direction | Frame payload before CRC | Meaning |
|---|---|---|
| Pi -> ESP32 | `C,2,SEQ,LEFT_RAD_S,RIGHT_RAD_S` | Set signed wheel rad/s targets; converted magnitude must not exceed 4000 counts/s |
| Pi -> ESP32 | `X,2,SEQ` | Stop immediately and reset both wheel controllers |
| ESP32 -> Pi | `S,2,ACK,ESP_MS,LEFT_COUNT,RIGHT_COUNT,LEFT_CPS,RIGHT_CPS,LEFT_PWM,RIGHT_PWM,STATUS` | State and acknowledgement telemetry |

Command fields accept finite decimal/scientific notation with a decimal point (`.`),
no whitespace, NaN, infinity or hexadecimal numbers. Version 1 is rejected to prevent
confusing counts/s with rad/s. Both command and state frames now carry version 2.

`include/ros_wheel_units.h` centralizes preliminary left/right calibration at
**4185 counts/revolution**, from the builder's approximate 41850 counts over ten
full wheel rotations on each wheel. This is a reported estimate, not a recorded
calibration acceptance test. Conversion is `counts/s = rad/s * 4185 / (2*pi)`;
1 rad/s is approximately 666.06344 counts/s. The per-wheel command limit is
`4000 * 2*pi / 4185` rad/s (approximately 6.0054). Shared PID and keyboard units
remain counts/s. Invalid values do not acknowledge a sequence or renew the lease.

The Pi plugin sends wheel rad/s directly in `C,2` frames with CRC and
new sequence numbers, and converts raw `S,2` feedback using `2*pi / 4185`.
It implements count wraparound, reboot/reset, stale telemetry, reconnect and
activation/deactivation checks. Initial physical operation is recorded; measured fault-response acceptance remains pending.
A USB reconnect without an ESP32 reboot retains the last sequence: the host must
synchronize rather than assume its sequence can restart at zero.

`SEQ`/`ACK` are unsigned 32-bit sequence numbers. Only newer command sequences are
accepted, using wraparound-safe comparison. A valid zero/zero command and `X` both
stop immediately. Invalid version, format, checksum, range, overflow, duplicate, or
older sequence does not refresh the watchdog. The ESP32 boots stopped. On connection, the host synchronizes its sequence
and requires an acknowledged stop; it does not replay the previous target.

Status bits are latched until reboot in this first implementation:

| Bit | Value | Meaning |
|---:|---:|---|
| 0 | `0x0001` | Command watchdog expired |
| 1 | `0x0002` | Receive buffer overflow |
| 2 | `0x0004` | Invalid frame format/version |
| 3 | `0x0008` | Invalid CRC |
| 4 | `0x0010` | Wheel target out of range |
| 5 | `0x0020` | Duplicate or stale sequence |

This protocol has firmware builds and parser/CRC tests. The Pi-side plugin under
`ros_ws/src/my_bot` was used in the [physical demonstration](../results/2026-09-10-real-room-mapping-navigation.md);
revision-pinned watchdog, disconnect and fault-response measurements remain pending.

## ROS 2 interfaces

The package is `ros_ws/src/my_bot`. Its `my_bot/Esp32System` plugin exports two
wheel rad/s command interfaces and radians/rad/s state interfaces. The configured
`diff_drive_controller` receives `geometry_msgs/msg/TwistStamped` at
`/diff_drive_controller/cmd_vel`, publishes `/diff_drive_controller/odom`, and owns
`odom -> base_link`. The ESP32 remains a non-ROS serial endpoint.

Preliminary geometry is wheel radius 0.040 m, separation 0.205 m, outer width
0.215 m, front/rear axle extents 0.180/0.080 m. These supersede the historical
0.233 m separation. `base_link` is at floor height under the axle midpoint; +X
points toward the front caster, +Y left, +Z up. The provisional laser scan plane
is centered at z=0.10 m, level/yaw zero. Final loaded dimensions remain uncalibrated.

ROS bringup defaults to Gazebo; `mode:=hardware` requires `serial_device` explicitly.
Hardware uses wall time; simulation uses `/clock`. The host requires fresh v2
telemetry and an acknowledged stop at startup. Telemetry or ACK stalls above 200 ms,
new status faults, reboot/time regression or I/O failure fault control and attempt
a stop. Reconnection is deliberate. Previously latched firmware bits are logged;
repeated occurrences of the same bit are not observable. The ESP32 watchdog remains
independent. See [hardware operation](../ros_ws/src/my_bot/HARDWARE.md).

## TF and mapping

Configured tree: `map -> odom -> base_link -> laser`. SLAM Toolbox owns
`map -> odom` in the separate SLAM launch; diff_drive_controller owns `odom -> base_link`;
robot_state_publisher owns robot link transforms. The simulated scanner publishes
`/scan` in `laser` at 15 Hz. The physical demonstration uses upstream `rplidar_ros`
with the A1M8 on GPIO UART (`/dev/ttyAMA0`, 115200 baud). Simulation uses `/clock`;
physical operation uses wall time. Map resolution is 0.05 m/cell. Manual map export saves YAML
and an occupancy image. The operator saves the map explicitly.

Offline transport/model checks, simulated mapping and initial physical mapping,
map saving and saved-map navigation are recorded. Physical fault timing, calibrated
odometry and repeated mission acceptance remain pending; see [testing](testing.md)
and the [capability summary](../ROADMAP.md).

## Nav2 simulation interfaces — September 8, 2026

`nav_sim.launch.py` composes simulation + live SLAM + Nav2, using `/clock`.
`/navigate_to_pose` accepts `nav2_msgs/action/NavigateToPose` in map coordinates.
NavFn plans using the live `/map`; local obstacles come from `/scan`; navigation
reads `/diff_drive_controller/odom`. The Nav2 collision radius is 0.215 m plus
0.005 m padding, conservatively enclosing the offset robot footprint.

Controller and recovery behaviors publish TwistStamped to `/cmd_vel_nav`;
velocity_smoother outputs TwistStamped to `/cmd_vel_smoothed`; collision_monitor
outputs TwistStamped to `/diff_drive_controller/cmd_vel`. Commands are capped
at 0.20 m/s and 0.6 rad/s, with 0.3 m/s² and 1.5 rad/s² acceleration limits.
The smoother input timeout is 0.2 s; monitor scan timeout is 0.5 s; existing wheel
command timeout is 0.25 s. These settings are not measured stopping guarantees.

Teleop must be stopped before launching Nav2 because it directly publishes to the
wheel controller, bypassing this pipeline. Mode switching currently uses separate
exclusive launch sessions; there is no automatic command multiplexer. Initial physical saved-map navigation is recorded separately. Autonomous frontier
selection is outside the current demonstrated scope.

### Navigation TF timing (September 8, preliminary simulation tuning)

SLAM map->odom publication remains scan-stamped with a 1.5 s transform_timeout
margin. DWB, global costmap, behavior server and BT navigator use a bounded 1.5 s
transform_tolerance. Local costmap and collision monitor retain 0.2 s. These
parameters have different framework semantics (publication offset vs lookup wait
or acceptable transform age); they are not motor or overall goal timeouts.
The change is a mitigation for reported TF aborts pending PC runtime verification.

Navigation planner fallback tolerance is 0.15 m; final approach tolerance remains
0.08 m relative to the planned endpoint. Costmap publication may use incremental
`costmap_updates` messages; consumers must subscribe to updates as RViz does.
Internal costmap update rates and obstacle resolution are unchanged.

## ROS keyboard mode — September 9, 2026

`teleop_wasd` accepts boolean `latched` (default false). False retains the 0.2 s
key-repeat expiry. True retains W/A/S/D motion until a replacement direction or
stop key; X, Space and unrecognized input select zero. Uppercase letters also work.
Commands remain fresh TwistStamped messages at the existing loop rate. Controller
and firmware timeouts are unchanged; they detect lost command publication, not
operator inactivity or an SSH outage while teleop continues publishing. Do not
run this direct publisher concurrently with Nav2.

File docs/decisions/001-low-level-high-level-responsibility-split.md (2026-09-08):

# 001: Separate low-level control from ROS autonomy

**Status:** Accepted as intended architecture  
**Date:** 2026-09-01 (migrated from the initial README; original decision date not recorded)

## Context

The initial repository README describes a differential-drive robot with an ESP32 and a future Ubuntu 24.04/ROS 2 Jazzy computer. Timing-sensitive actuator and sensor acquisition work needs different failure and scheduling behavior from mapping and navigation workloads.

## Decision

The ESP32 will own direct motor outputs, encoder sampling, local wheel-speed control, command-loss handling, and immediate actuator-safe behavior. The ROS computer will own hardware bridging, robot model/TF coordination, sensor processing, state estimation, SLAM, localization, Nav2, and mission-level autonomy.

ESP32 encoder-feedback wheel control now exists. The Pi transport and ROS package source now exist in `ros_ws/src/my_bot`; autonomous mapping remains planned. This record sets ownership; it does not assert that planned components are implemented.

## Alternatives considered

The Git history does not record evaluated alternatives. In particular, it does not establish whether motor control on the ROS computer, micro-ROS on the ESP32, or a standard `ros2_control` hardware architecture was explicitly compared.

## Reasoning

The split preserves deterministic, local handling of actuator timing and command loss while allowing compute-heavy autonomy to use established ROS 2 packages. It also avoids making a networked or general-purpose process the only path to a safe actuator state.

## Consequences

- The microcontroller-to-computer protocol must carry commands, timestamps/validity, feedback, and diagnostics with defined failure behavior.
- Safety must be layered; ESP32 stop behavior does not replace independent power isolation or system hazard analysis.
- ROS-side implementations should reuse standard ROS 2, `ros2_control`, `robot_localization`, SLAM Toolbox, and Nav2 interfaces where appropriate.
- Decision 002 resolves the transport and odometry boundary: a Pi-side `ros2_control` hardware plugin uses a versioned serial link to the ESP32, and the standard differential-drive controller computes ROS wheel odometry from returned state.

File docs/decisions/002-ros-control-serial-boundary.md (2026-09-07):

# 002: Use ros2_control on the Pi and a serial-controlled ESP32

**Status:** Accepted as intended architecture
**Date:** 2026-09-04

## Context

The robot needs to accept velocity commands from ROS 2 while retaining deterministic
motor control and command-loss stopping on the ESP32. The ESP32 currently runs
encoder-feedback wheel PID and has no ROS client or framed transport.

## Decision

ROS 2 Jazzy will run on the Raspberry Pi. A custom C++
`hardware_interface::SystemInterface` will connect `ros2_control` to the ESP32 over
USB serial. The standard `diff_drive_controller` will convert body velocity commands
into left/right wheel velocity commands and compute wheel odometry from returned
joint feedback.

The ESP32 will not be a ROS node and will not use micro-ROS in the first version. Its
ROS-serial firmware will accept framed wheel targets, run the existing local PID,
enforce its own watchdog, and return encoder/controller state.

## Reasoning

- It retains local, deterministic actuator behavior if the Pi or ROS process stalls.
- It lets Nav2 and teleoperation use standard ROS controller interfaces.
- It avoids placing DDS, ROS executors, and ROS distribution compatibility on the
  small controller.
- It gives simulation and physical hardware the same wheel-level ROS interface.

## Consequences

- The Pi-side hardware plugin owns feedback-unit conversion and serial reconnect behavior.
  Decision 004 moves command rad/s-to-counts/s conversion into the ROS-only ESP32 adapter.
- The wire protocol must be versioned, bounded, testable, and independent of ROS
  message serialization.
- Encoder counts per revolution, loaded wheel radius, and wheel separation must be
  measured before odometry can be accepted.
- The ESP32 is indirectly controlled by ROS, but it does not literally subscribe to
  a ROS topic.

## Alternatives considered

- **micro-ROS on ESP32:** rejected for the first version because it adds executor,
  transport-agent, memory, and ROS-version complexity without improving the local
  PID boundary.
- **Custom ROS bridge node without ros2_control:** viable for early experiments, but
  rejected as the target architecture because it would duplicate standard wheel
  command/state integration.
- **Motor PID on the Raspberry Pi:** rejected because USB/OS scheduling and Pi failure
  must not be the only protection against stale actuator commands.

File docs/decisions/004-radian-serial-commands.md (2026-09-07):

# 004: Accept wheel rad/s in ROS-serial firmware

**Status:** Accepted, implemented; physical validation pending
**Date:** 2026-09-07

At the builder's request, version 2 accepts left/right wheel rad/s and converts
commands on the ESP32 in a ROS-only adapter. Shared PID and the default keyboard
build retain counts/s and unchanged behavior. Preliminary calibration is 4185
counts/revolution on both wheels (approximately 41850 over ten turns reported).
Constants are centralized in `include/ros_wheel_units.h`.

Version 1 is rejected because silently reinterpreting existing counts/s commands
as rad/s is unsafe. CRC, sequence checks, watchdog, explicit stop and the equivalent
4000 counts/s bound remain. Feedback retains raw counts/counts/s, with version 2.

The Pi still needs a custom ros2_control SystemInterface for USB framing,
sequence/reconnect handling, feedback conversion and lifecycle safety. It sends
wheel rad/s directly; ESP32 does not become a ROS subscriber. This amends command
conversion ownership in decision 002 without moving the wheel PID to the Pi.

Compile and native tests cannot establish ROS or physical compatibility; upload,
watchdog/reconnect tests and integrated Pi validation are still required.

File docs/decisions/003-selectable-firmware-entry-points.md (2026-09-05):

# 003: Keep keyboard and ROS-serial firmware as separate selectable builds

**Status:** Accepted for the next firmware change
**Date:** 2026-09-04

## Context

The known keyboard/PID firmware must remain available while a ROS-ready serial entry
point is developed. Two Arduino source files that both define `setup()` and `loop()`
cannot be linked into one PlatformIO build.

## Decision

Keep `src/main.cpp` as the keyboard entry point and add `src/main_ros.cpp` for the
ROS-serial entry point. Add `keyboard` and `ros_serial` PlatformIO environments with
source filters so exactly one entry point is compiled. Set `keyboard` as the default
environment so an ordinary build/upload preserves current behavior.

Shared motor, encoder, PID, ramp, and safety logic must be extracted into reusable
code rather than copied into two independently drifting implementations.

## Consequences

- `pio run` continues to build the keyboard firmware by default.
- `pio run -e ros_serial` explicitly builds the serial-controlled firmware.
- Both builds must pass after any shared drivetrain change.
- Adding the second entry point requires a behavior-preserving refactor of the current
  monolithic firmware before the new protocol is layered on top.

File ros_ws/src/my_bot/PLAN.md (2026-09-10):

# Historical package development notes

These dated entries describe earlier development stages, not current status.
See the [package README](README.md) and [current execution plans](../../../docs/plans/active/)
for ongoing work.

# Preliminary robot description

Date: 2026-09-06. Scope: a simple Jazzy-targeted kinematic description and preview.

- Implement measured wheel layout and builder-approved 26 cm envelope.
- Keep the chassis/caster simple and record assumptions explicitly.
- Use the builder-authorized provisional centered LiDAR mount, scan plane 0.10 m
  above floor (0.06 m above wheel axles); confirm before real mapping.
- Provide a real-description launch and a separate GUI-only preview launch.
- Expand Xacro, check geometry/frame connectivity, and inspect Python/YAML syntax.
- On the Pi: colcon build/test, inspect RViz, verify forward/left axes and wheel
  motion, then compare geometry with the assembled robot.

This preliminary description is not acceptance evidence for motion, odometry,
collision avoidance or SLAM. Encoder calibration, hardware plugin, final mounting
measurements and integrated tests remain separate tasks.

Status: local validation passed with Xacro 2.1.1: expansion with/without LiDAR, connected frame trees, wheel spacing/radius/width and footprint extents, Python launch syntax, package XML, RViz YAML, and git diff --check. Generated robot.urdf saved. Jazzy colcon build/test and RViz runtime remain pending; ROS is not installed in this macOS environment.

LiDAR revision: enabled provisional laser frame and visual cylinder; mount assumptions
are documented. Local expansion and transform checks passed; ROS runtime pending.

## Estimated simulation extension

Builder requested estimated masses/inertias, contact settings, gz_ros2_control,
and a simulated LiDAR. Added a conditional Gazebo model, controller configuration,
clock/scan bridge, local test room and separate simulation launch. Estimates and
real-hardware limitations are in SIMULATION.md. Four local automated checks passed: all four simulation/LiDAR combinations,
connected frame trees, positive inertias and 1.6 kg mass totals, controller/geometry
consistency, sensor and bridge wiring, and XML/Python/YAML syntax. The generated
URDF was refreshed and git diff --check passed. colcon/Gazebo/WSL runtime checks
remain pending because ROS and Gazebo
are not installed here. The real ESP32 SystemInterface is still not implemented.

## ESP32 hardware and selectable bringup — 2026-09-07

Implemented `my_bot/Esp32System`, serial v2 transport, pluginlib export/build rules,
opt-in hardware Xacro and launch, and default-simulation bringup switch. Added
separate real/sim clocks, common conservative limits and WSL/Pi instructions.
Offline verification: pseudo-terminal transport/fault tests, model/configuration
checks and Python/XML syntax. Jazzy compile/plugin loading and Gazebo/WSL runtime
remain pending on Ubuntu; physical acceptance remains pending on the Pi.
This supersedes earlier statements that the hardware plugin does not exist.

## WASD teleoperation — 2026-09-07

Added a shared stamped-command terminal executable for simulation and hardware.
W/S select forward/reverse; A/D turn; space/X/unknown keys stop. Monotonic 0.2 s
key expiry prevents stale input from persisting when simulation time pauses.
Mapping, repeat/expiry and invalid-speed tests pass offline. ROS/terminal integration
still requires Ubuntu. Updated dependencies, install rules and operation commands.

## User-observed simulation result — 2026-09-07

Recorded [initial simulation implementation](docs/results/2026-09-07-initial-simulation.md) with the builder's original photo. Gazebo launch, WASD driving,
10 Hz simulated scans and RViz display were reported working. The screenshot
confirms visible scan returns with RViz status Ok. This supersedes earlier pending
statements for the initial simulation smoke test only; physical validation,
repeatable startup, odometry accuracy and SLAM remain pending.

## Simulation SLAM and obstacle room — 2026-09-07

Bounded scope: add five static obstacles, a simulation-only async SLAM Toolbox
launch, matching frame/clock/range parameters, an overhead RViz map display,
and manual map-saving instructions. Keep hardware and default teleop behavior.
Verify offline model/configuration/world checks; builder must validate /map,
map->odom, slow driving/loop closure and saved YAML/image in WSL.

SLAM step offline verification: eight model/configuration/world tests and three
WASD tests passed; git diff --check passed. WSL SLAM/map-export testing is pending.

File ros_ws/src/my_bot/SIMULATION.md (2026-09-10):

# Simulation, mapping and navigation

Use Ubuntu 24.04, ROS 2 Jazzy and Gazebo Harmonic with a working graphics environment.
Complete the [build steps](README.md#build), then source ROS and the workspace in
each terminal. The Pi and ESP32 are not needed for simulation.

## Choose a mode

Run one of these launches at a time; each starts Gazebo, controllers and RViz.
Stop the previous launch and teleop before switching modes.

| Mode | Command |
|---|---|
| Drive with laser visualization | `ros2 launch my_bot bringup.launch.py` |
| Build a map while driving | `ros2 launch my_bot slam_sim.launch.py` |
| Navigate while SLAM builds the map | `ros2 launch my_bot nav_sim.launch.py` |

The local world contains four boundary walls and six interior box obstacles.
Gazebo supplies wheel feedback and simulated LiDAR; `diff_drive_controller`
publishes odometry. `/clock` and `/scan` are bridged to ROS. All simulated nodes
use `use_sim_time:=true`.

## Drive and map

With the driving or mapping launch running, use a second sourced terminal:

```bash
ros2 run my_bot teleop_wasd --ros-args \
  -p use_sim_time:=true -p frame_id:=base_link -p speed:=0.1 -p turn:=0.5 \
  -r cmd_vel:=/diff_drive_controller/cmd_vel
```

Hold W/S to drive forward/reverse and A/D to turn. Space or X stops; Ctrl+C exits.
The default teleop expires after 0.2 s without a key repeat. Keep the terminal focused.
Drive slowly around obstacles, then return near the starting position to inspect
map consistency. RViz shows free, occupied and unknown space with red laser returns.

Useful checks in another sourced terminal:

```bash
ros2 control list_controllers
ros2 topic hz /scan
ros2 topic echo /diff_drive_controller/odom --once
```

Both controllers should be active, scans should use frame `laser` at the configured
15 Hz, and odometry should change while driving. During mapping, also check:

```bash
ros2 lifecycle get /slam_toolbox
ros2 topic echo /map --once --field info
ros2 run tf2_ros tf2_echo map odom
```

SLAM should be active with a nonempty map and a `map → odom` transform.
`diff_drive_controller` owns `odom → base_link`; `robot_state_publisher` owns the
robot link transforms. Persistent missing-map or TF errors need investigation.

## Save a map

While SLAM is running, choose a new basename for each run:

```bash
mkdir -p ~/robot_maps
ros2 run nav2_map_server map_saver_cli -f ~/robot_maps/room_01 --ros-args \
  -p use_sim_time:=true -p map_subscribe_transient_local:=true -p save_map_timeout:=10.0
```

Keep the YAML and its referenced occupancy image together. Reusing the basename
replaces the saved files. This exports an occupancy map; it does not save SLAM
Toolbox's resumable pose graph. Record selected runs under [results](../../../results/README.md).

## Nav2 goals

Stop teleop and the old launch, then start `nav_sim.launch.py`. Wait for the map
and Nav2 activation. Select **Nav2 Goal** in RViz, click in known free space, and
drag to choose the final heading. Use **Cancel** in Navigation 2 to cancel a goal.
Live SLAM estimates the pose in this mode, so no AMCL initial pose is needed.

NavFn plans a path, DWB tracks it, and velocity smoothing and collision monitoring
feed stamped commands to `/diff_drive_controller/cmd_vel`. Teleop publishes directly
to that controller; do not run it concurrently with Nav2.

| Setting | Configured value |
|---|---|
| Navigation speed limits | 0.20 m/s, 0.6 rad/s |
| Collision radius / padding | 0.215 m / 0.005 m |
| Wheel command timeout | 0.25 s |
| Collision-monitor scan timeout | 0.5 s |

These are simulation settings, not measured physical stopping guarantees.
Goals must lie in observed free space. The physical demonstration uses a saved
map with AMCL instead; see the [hardware guide](HARDWARE.md#mapping-and-navigation).

If only RViz is missing, open the UI without starting another simulation:

```bash
ros2 launch my_bot rviz_navigation.launch.py
```

## Model assumptions and verification

[simulation_parameters.xacro](description/simulation_parameters.xacro) centralizes
estimated mass (1.6 kg), inertias, friction and scanner properties. The scanner uses
360 samples at 15 Hz over 0.15–6 m with 0.01 m simulated range noise. Velocity control
does not reproduce the ESP32 PI loop or USB timing. GPU LiDAR needs a rendering
context even when RViz is disabled.

Initial driving and [interactive SLAM](../../../results/2026-09-08-simulated-lidar-slam.md)
are recorded. Repeatable Nav2 acceptance should cover a nearby goal, a path around
an obstacle, cancellation, an unreachable goal and a fresh restart. Record source
revision, configuration and outcomes; offline checks do not establish obstacle avoidance.

Detailed contracts and provisional TF timing settings are in
[interfaces](../../../docs/interfaces.md); earlier tuning history is retained in
[plan 008](../../../docs/plans/active/008-nav2-simulation.md).

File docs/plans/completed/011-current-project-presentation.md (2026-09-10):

# Current project presentation — September 10, 2026

Accepted scope: present teleoperated SLAM mapping followed by Nav2 autonomous
path planning and navigation to operator-selected destinations. Remove automatic
destination selection and future-work sections from the current project overview
and user guides. Preserve runtime code and historical evidence.

Updated the README, architecture, capability summary, presentation/media pages,
ROS platform workflow and current mapping/navigation guides. Removed the optional
exploration workflow from the WSL guide and its section in the interface/testing
references. The former plan 009 is retained as a withdrawn historical record.
No physical verification claims were added, and the demonstrations still identify
operator-selected goals. Existing unrelated working changes were preserved.

Verification: inspect the documentation diff, check local links and whitespace,
and syntax-check the edited guide's Bash blocks. No executable code changes.

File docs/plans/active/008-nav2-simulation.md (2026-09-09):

# Nav2 click-to-go simulation

2026-09-08. Implement a separate simulation launch combining existing SLAM/Gazebo
with standard Nav2 planner, controller, behaviors, navigator, velocity smoother
and collision monitor. Configure conservative circular collision bounds enclosing
the offset robot footprint, known-space planning, stamped commands and sim time.
Do not implement frontier exploration, AMCL, physical navigation or new firmware.
Existing WASD-only and SLAM-only launches remain available.

Acceptance: offline configuration/launch checks; Jazzy build/test and runtime
startup; goal reached around an obstacle; canceled goal stops motion; blocked goal
fails without collision; SLAM updates while moving; repeat on a fresh launch.
Mac offline checks cannot establish Linux/Gazebo/physical acceptance.
Update the copy/paste WSL guide with dependencies, goals, cancellation and logs;
commit and push the implementation and explicitly report runtime limits.

## Implementation and offline verification

Added navigation.launch.py, nav_sim.launch.py, nav2.yaml and navigation.rviz;
registered dependencies, installation and navigation tests. Updated WSL workflow
and NAVIGATION.md with goals, cancellation, diagnostics and manual-mode switching.
Fourteen offline checks passed (3 navigation, 8 model, 3 teleop); one ROS-dependent
launch/install/clock test skipped on macOS. Bash documentation syntax and diff
whitespace checks passed. No firmware change. ROS/colcon/Gazebo is unavailable on
this Mac, so target build, new hardware-plugin test and runtime acceptance remain
pending on the PC. Do not mark this plan complete until the runtime criteria pass.

## RViz launch bug correction — September 8

User reported Terminal 1 never opened RViz; manual old SLAM view opened without
Nav2 controls. Found rviz=false launch-argument leakage from unscoped child includes
in both nav_sim and slam_sim. Isolated overrides with scoped GroupAction, retained
parent rviz option and enabled process output. Added rviz_navigation.launch.py for
opening the correct navigation UI independently and updated the WSL workflow.

Fifteen offline tests passed; two ROS-only tests skipped. The new static regression
was also run against the prior committed nav_sim launch and correctly failed.
The ROS-only regression evaluates both parents with rviz=true/false using actual
launch scoping, replacing external backends and never starting processes. Target
ROS tests and actual WSL window visibility remain pending. No firmware changes.

Source semantics checked in ros2/launch Jazzy actions/include_launch_description.py
and actions/group_action.py: include arguments become SetLaunchConfiguration;
scoped groups push/pop configurations. This is a launch defect, separate from the
previous shader warning investigation.

## Map-transform abort mitigation — September 8

Reviewed launch clock propagation, TF frame ownership, DWB configuration, SLAM
TF publication and command-chain settings. No frame-name mismatch found in the
checked configuration. Upstream Jazzy DWB rejects an extrapolated lookup when the
latest transform exceeds transform_tolerance; ControllerTFError aborts immediately
rather than using failure_tolerance. SLAM publishes scan-stamped map->odom TF plus
transform_timeout. Thus increasing goal patience would not address this error.

Raised SLAM's TF margin and DWB/global-costmap/behavior/navigator transform
allowances to 0.5 seconds. This is a bounded timing mitigation, not a confirmed
root-cause fix: the PC's failing transform timestamps are unavailable. Kept local
odometry and collision-monitor allowances, sensor expiry, velocity limits,
footprint and watchdogs unchanged. Did not restamp old observations as current.
Updated WSL diagnostic commands to capture individual TF links, odometry stamps,
clock publishers, node clocks and effective timing parameters; added launch-log
capture for the preceding upstream error details.

Verification: 15 offline tests passed, 2 ROS-dependent tests skipped; diff check
passed. ROS/Gazebo/colcon is unavailable on this Mac. Goal completion and physical
Pi acceptance remain unverified; repeat the runtime acceptance tests on the PC.

References checked:
- https://github.com/ros-navigation/navigation2/blob/jazzy/nav2_dwb_controller/nav_2d_utils/src/tf_help.cpp
- https://github.com/ros-navigation/navigation2/blob/jazzy/nav2_controller/src/controller_server.cpp
- https://github.com/SteveMacenski/slam_toolbox/blob/jazzy/src/slam_toolbox_common.cpp

## Follow-up: larger simulation TF allowance

User reports continued difficulty at 0.5 s and requested substantially more
buffer. Increased SLAM transform_timeout and DWB/global-costmap/behavior/navigator
transform_tolerance to 1.5 s. This permits older map corrections and is provisional
simulation tuning, not verified physical-robot tuning. It does not repair missing
TF or mixed clocks. The scan rate remains 10 Hz: increasing it adds processing
load and does not establish that observations will arrive sooner on an overloaded
WSL host. Local-costmap and collision-monitor transform tolerances remain 0.2 s;
sensor expiry and motor watchdogs remain unchanged.

Offline verification: 15 tests passed, 2 ROS-only tests skipped. Runtime goal
completion still needs PC verification; prior 0.5 s mitigation was insufficient
according to the user. If the same abort persists, inspect the preceding TF error
and timestamps from nav2-launch.log before increasing allowances again.

## Faster simulation — September 8

Nav2 linear speed increased from 0.12 to 0.18 m/s, with the simulation drivetrain
cap raised to 0.20 m/s. Turning and acceleration limits are unchanged. Simulated
LiDAR increased from 10 to 15 Hz; SLAM minimum_time_interval reduced from 0.1 to
0.05 s so it can accept the faster scan stream. Travel thresholds still apply.
Physical driver/controller limits and default WASD speeds are unchanged. Faster
scans add processing load; runtime timing and navigation acceptance remain pending.
Tests now permit intentional simulation/hardware speed differences while still
checking matching geometry/settings, physical wheel limits and simulated wheel
limits. Offline suite: 15 passed, 2 ROS-dependent skipped.

## Small performance pass — September 8

Accepted scope: improve performance without reducing collision checking or
rewriting the navigation stack. Reviewed navigation/SLAM parameters, visualization
subscriptions, build configuration and host serial/plugin implementation.

- Navfn fallback goal tolerance: 0.08 -> 0.15 m. The goal checker still uses
  0.08 m relative to the selected path endpoint, preserving final approach control.
- Simulation Nav2/smoother speed: 0.18 -> 0.20 m/s, matching the existing simulation
  drivetrain cap. Turning, acceleration, scan rate, collision footprint, obstacle
  resolution/update rates, recovery behavior and stop timeouts are unchanged.
- Costmaps use standard incremental publication rather than forcing full maps.
  RViz already subscribes to the local costmap update topic. Full internal maps
  remain available for planning/collision checking; bandwidth savings depend on
  changed area and subscribers (rolling maps may still require full updates).
- Default native build is RelWithDebInfo when no build type is selected: optimized
  plugin/serial code with debugging symbols. Explicit Debug or other choices are
  preserved. Tests already use -UNDEBUG so assertions remain enabled.

No speculative serial refactor or planner algorithm replacement: neither has a
measured bottleneck here. Slow motion may still be necessary near obstacles and
goals, or result from simulation running slower than real time. No measured CPU
or navigation speedup is claimed. Pi physical speed settings remain unchanged;
this shared navigation configuration is still pending physical integration.

Verification: 16 offline Python checks passed, 2 ROS-only skipped. Native transport
suite passed with -O2 -g -UNDEBUG, covering CRC, sequence/wraparound, handshake,
reconnect and stale/reboot responses. Diff check passed. Linux colcon, incremental
RViz updates and goal completion still require target runtime verification.

Official parameter semantics:
https://docs.nav2.org/jazzy/configuration_and_development/configuration_guide/planners_plugins/configuring_navfn/
https://docs.nav2.org/jazzy/configuration_and_development/configuration_guide/core_servers/costmap_2d/

## Real-robot preparation documentation

Added Option B to WSL_COPY_PASTE.md: Pi SSH/install/build, explicit firmware upload,
serial identification, real hardware launch, PC RViz networking/real-time settings,
low-speed teleop, optional upstream A1 LiDAR bringup, and remaining physical
mapping/Nav2 prerequisites. Corrected stale hardware/simulation speed equivalence
in HARDWARE.md. No launch/firmware changes or physical acceptance claimed.
Verified documented hardware launch arguments and RViz config against source,
A1 arguments against upstream, and WSL networking against Microsoft documentation.
All 26 Bash blocks in the combined guide passed bash -n; git diff --check passed.
Commands were not executed against a Pi or physical robot.

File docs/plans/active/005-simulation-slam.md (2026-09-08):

# Simulation SLAM Toolbox and obstacle room

Date: 2026-09-07. Status: implemented; initial occupancy-map visualization recorded; full runtime acceptance pending.

Scope: extend the sibling my_bot test room to six interior boxes; add a separate
slam_sim.launch.py using the standard Jazzy online_async_launch.py, /scan,
base_link/odom/map frames, simulation time and 5 cm map resolution. Add RViz
occupancy-map display with an overhead view and manual map-saving instructions.
Keep physical hardware, Nav2 navigation and autonomous exploration out of this step.

Verification: eight offline model/configuration/world tests and three WASD tests
passed. Tests check scan ranges, frames/clock, map QoS, obstacle count/nonoverlap,
spawn clearance and Python/XML/YAML syntax. ROS/Gazebo is unavailable on this Mac;
the previous builder-observed simulation result does not validate this new SLAM launch.

Acceptance remaining on WSL: update/build/test, start only slam_sim.launch.py,
confirm SLAM active and /map plus map->odom, drive a loop around obstacles, inspect
map consistency, save a YAML/image and record the result. Commands are in my_bot/SLAM.md.
No firmware changes in this step. Physical watchdog and Pi integration remain pending.

## Repository consolidation — 2026-09-07

The full ROS package is now in `ros_ws/src/my_bot` in this repository. Earlier
sibling-package references are historical. Source behavior and pending physical
acceptance are unchanged. See [current status](../../../ROADMAP.md).

## Initial SLAM screenshot — 2026-09-08

The owner supplied a screenshot showing Gazebo and an occupancy map with scan
overlay in RViz. Added the unchanged image and a brief color/view explanation to
the project README and [dated record](../../../results/2026-09-08-simulated-lidar-slam.md).
This establishes initial simulated SLAM visualization. Capture revision, repeatable
startup, loop consistency and map export remain unverified; the plan stays active.
Image integrity, local documentation links and diff whitespace checks passed.

## Compact room — September 8

User confirmed interactive WSL SLAM works (Gazebo, RViz, driving and updating map).
See the dated result. Requested smaller enclosure: reduce wall-center span from
4 m to 3 m, floor from 6 m to 3.1 m, retain four 0.5 m high walls and six obstacles.
Reposition and resize obstacles to preserve clear spawn and wall clearance.
Existing geometry tests now check enclosure dimensions as well as obstacle bounds.
All eight offline model/configuration checks passed, including wall geometry,
obstacle bounds/nonoverlap and spawn clearance; git diff --check passed.
ROS/Gazebo is unavailable on this Mac; revised room needs a PC smoke test. Nav2 explanation
is planning only, with no Nav2 implementation in this change.

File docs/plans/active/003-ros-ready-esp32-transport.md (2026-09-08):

# ROS-ready ESP32 transport and selectable firmware builds

**Status:** Source implemented — physical acceptance pending
**Owner:** Builder with Codex implementation support
**Created:** 2026-09-04
**Updated:** 2026-09-07
**Related roadmap milestone:** ROS-ready ESP32 command interface

## Goal

Add a separately selectable, ROS-ready serial firmware build for the ESP32 while
preserving the current keyboard/PID build and its behavior. Validate its protocol
logic before depending on Raspberry Pi or ROS installation.

## Current State

`src/main.cpp` is the keyboard Arduino entry point; `src/main_ros.cpp` is separately selected. It implements keyboard commands,
encoder acquisition, 50 Hz wheel control, PID/feed-forward, target ramps, PWM output,
and timeouts. It builds and its controller unit test passes. A raised-wheel test of
the preceding 400 ms straight ramp showed stable +/-3000 counts/s tracking. The
current 300 ms straight and 100 ms turn ramps still require physical validation.

`main_ros.cpp`, the framed protocol, parser tests, the second PlatformIO environment,
now exist and pass automated checks. They have not been
physically tested. The ROS package is included at `ros_ws/src/my_bot`; see plan 004.

## Inputs

- Current GPIO map, polarity, controller limits, and measured encoder signs.
- Proposed serial contract in `docs/interfaces.md`.
- Decisions 001, 002, and 003 under `docs/decisions/`.
- Preliminary builder measurement: approximately 41850 counts/10 turns on each wheel
  gives 4185 counts/revolution. Version 2 commands use rad/s; feedback retains raw units.

## Outputs

- `src/main_ros.cpp` as a thin ROS-serial firmware entry point.
- `keyboard` and `ros_serial` PlatformIO environments with exclusive source filters.
- Shared drivetrain runtime used by both entry points without behavioral duplication.
- Fixed-buffer protocol parser/encoder with automated tests.
- Updated interface/build documentation and verification results.

## Requirements

1. The default `pio run` build must preserve keyboard firmware behavior.
2. `pio run -e ros_serial` must compile only `main_ros.cpp` as the Arduino entry point.
3. Both entry points must reuse one implementation of motor output, encoder sampling,
   target ramps, PID, polarity, output limiting, and stop behavior.
4. Protocol parsing must not allocate Arduino `String` objects or accept unbounded
   input; use a fixed buffer and reject overflow.
5. Only valid, in-order command frames refresh the 250 ms motion watchdog.
6. Explicit stop, watchdog expiry, parser overflow, and boot must produce zero motor
   output. A single malformed frame does not refresh the lease; subsequent valid
   frames may recover unless a latched hardware fault is introduced later.
7. Commands use finite decimal rad/s; telemetry and sequences use fixed-width integer fields and the versioned framing,
   units, checksum, and limits specified in `docs/interfaces.md`.
8. Sequence wraparound must be handled intentionally; replayed/out-of-order frames
   must not extend motion.
9. Host disconnect/reconnect must never cause a previous command to resume.
10. Do not create the ROS workspace or fake hardware-dependent measurements in this
    task.

## Files / Components Involved

- `platformio.ini`
- `src/main.cpp`
- `src/main_ros.cpp` (new)
- focused shared files under `include/`, `lib/`, or `src/`
- `test/`
- `docs/interfaces.md`, `docs/testing.md`, `START_HERE.md`, and this plan

## Implementation Steps

1. Add tests around reusable command/watchdog/ramp behavior before moving code.
2. Extract the shared drivetrain runtime in small steps; build and test the keyboard
   firmware after each behavior-affecting step.
3. Add PlatformIO `keyboard` and `ros_serial` environments with `keyboard` as
   `default_envs`; verify source-filter behavior before adding the new entry point.
4. Implement and test the fixed-buffer frame parser, CRC-16/CCITT-FALSE calculation,
   range checks, and sequence handling without attached hardware.
5. Add `main_ros.cpp` using the shared drivetrain runtime and protocol implementation.
6. Add and test telemetry serialization.
7. Run automated checks and review boot, timeout, malformed input, integer bounds,
   timer wraparound, and reconnect behavior.
8. Perform a raised-wheel hardware test through the future Pi-side connection and record the result.
9. Update project state; do not mark the plan complete until every criterion passes.

## Automated Verification

- Current controller unit test.
- New native parser, CRC, sequence, bounds, watchdog, and frame-serialization tests.
- `pio run` for the default keyboard environment after it exists.
- `pio run -e keyboard` and `pio run -e ros_serial` after both environments exist.
- `git diff --check`.

Do not claim these new commands passed until their environments and tests exist.

## Hardware Verification

With wheels raised and independent motor-power removal available:

1. Boot/reboot with the host disconnected and verify no motion.
2. Send valid forward, reverse, turn, zero, and explicit-stop frames.
3. Stop frames for longer than 250 ms while moving and measure the stop latency.
4. Send bad CRC, malformed, overlong, stale-sequence, and out-of-range frames.
5. Disconnect and reconnect USB while the last command was nonzero.
6. Confirm telemetry signs, sequence acknowledgement, counts, measured speeds, PWM,
   and status flags.
7. Repeat safety-critical cases three times and record a dated result.

## Acceptance Criteria

- Both firmware environments build and all protocol/controller tests pass.
- The keyboard build retains its documented command behavior.
- The ROS-serial build accepts documented command frames and emits documented state frames.
- No invalid/stale input or disconnect can keep a motion lease alive beyond 250 ms.
- Explicit stop and boot produce zero commanded PWM.
- Protocol documentation and captured test frames agree byte for byte.
- A dated raised-wheel result records three successful timeout/disconnect trials.

## Progress

- 2026-09-07 — Updated only ROS firmware/protocol to version 2 rad/s commands,
  with ROS-only conversion constants at preliminary 4185 counts/revolution per wheel.
  Keyboard main and shared drivetrain/controller files unchanged. Both PlatformIO
  environments built successfully. Native controller and expanded protocol/conversion
  tests passed with clang++ C++11, warnings as errors. Tests cover decimal/scientific
  input, invalid/nonfinite/overflow values, version-1 rejection, CRC, sequence wrapping,
  buffer overflow, embedded NUL, conversion signs/zero/limits and state formatting.
  Physical validation and Pi plugin integration remain pending; plan stays active.

- 2026-09-06 — At builder request, the separate `my_bot` package now includes
  estimated 1.6 kg mass distribution/inertias, contact parameters, Jazzy
  `gz_ros2_control`, simulated LiDAR, a local room, controller configuration and
  simulation launch. Four local structural tests passed; no Gazebo/ROS runtime
  was available on this Mac. This does not implement the Pi serial hardware
  plugin or validate the ESP32; those tasks and physical acceptance remain open.

- 2026-09-06 — Created preliminary kinematic description in the separate sibling
  `my_bot` package at the builder's request; local Xacro/geometry/syntax checks
  passed. Revised geometry is recorded in interfaces and parts list. No ROS
  runtime or hardware validation occurred; the serial bridge remains unimplemented.

- 2026-09-05 — Simplified keyboard `e` output to left/right raw encoder counts only; periodic motion telemetry is unchanged. `pio run` and `git diff --check` passed. Upload and hardware verification pending.

- 2026-09-04 — Architecture and protocol specified.
- 2026-09-05 — Added mutually exclusive `keyboard` and `ros_serial` builds, shared drivetrain runtime, `main_ros.cpp`, fixed-buffer CRC/sequence parser, state framing, 250 ms watchdog, and protocol tests.
- 2026-09-05 — Both firmware environments built and the wheel-controller and protocol tests passed. Hardware validation remains pending.
- 2026-09-05 — Fixed receive overflow to report on the first excess byte and immediately call `RobotDrive::stop()`, without waiting for newline or watchdog expiry. Added parser regression checks for the buffer boundary, discarded frame remainder, and recovery on the next frame. On macOS, `pio run` (default keyboard) and `pio run -e ros_serial` passed using the installed PlatformIO executable; both native tests compiled with `clang++ -std=c++11 -Wall -Wextra -Werror -Iinclude` and executed successfully. Physical overflow-stop validation remains pending.

Pre-push check on 2026-09-05: both firmware environments built successfully with
`pio run -e keyboard -e ros_serial`; both native controller/protocol tests passed
with `clang++ -std=c++11 -Wall -Wextra -Werror -Iinclude`, and `git diff --check`
passed. The parts list now records the purchased Pi 5 kit and delivered RPLIDAR
A1M8. Builder-reported wheel separation (0.233 m) and radius (0.040 m) are recorded
as provisional geometry; encoder calibration and physical serial validation remain
pending.

## Decisions

- Use a Pi-side `ros2_control` plugin rather than micro-ROS; see decision 002.
- Use exclusive PlatformIO entry points rather than compiling two `setup()`/`loop()`
  definitions; see decision 003.
- Decision 004: ROS-only ESP32 adapter converts rad/s commands; feedback retains raw counts/counts-per-second.

## Problems / Blockers

- 2026-09-06 — Builder moved the motors. Ask for revised wheel separation and
  axle/chassis offsets before ROS motion/odometry configuration, and revised
  footprint/LiDAR offsets before TF/navigation setup. Previous geometry is stale;
  counts/s transport testing can proceed without these measurements.

- Preliminary 4185 counts/revolution per wheel needs repeatable calibration validation.
- Raspberry Pi 5 (8GB) and RPLIDAR A1M8 are identified in the parts list;
  Pi setup and physical serial validation remain pending.

## Results

Automated build and unit checks passed on 2026-09-05. No hardware result exists for the ROS-serial firmware.

## Follow-up Work

- Raspberry Pi OS/ROS installation and the `ros2_control` hardware plugin.
- Geometry calibration, robot description, odometry, LiDAR, TF, and SLAM.
- Nav2, frontier exploration, automatic startup, and map saving.

2026-09-07: Pi plugin source now exists in sibling my_bot; see active plan 004.
Its offline tests do not satisfy this plan's physical watchdog/reconnect criteria.

## Repository consolidation — 2026-09-07

The full ROS package is now in `ros_ws/src/my_bot` in this repository. Earlier
sibling-package references are historical. Source behavior and pending physical
acceptance are unchanged. See [current status](../../../ROADMAP.md).

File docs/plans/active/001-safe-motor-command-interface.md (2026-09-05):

# Safe, testable serial motor command interface

**Status:** Active  
**Owner:** Unassigned  
**Created:** 2026-09-01  
**Updated:** 2026-09-01  
**Related roadmap milestone:** Milestone 1 — motor and encoder hardware

## Goal

Validate deterministic command-loss and stop behavior for the ESP32 motor command paths, then record a controlled bench validation of both channels.

## Current State

`src/main.cpp` uses GPIO 25/26 and 32/33 as BTS7960 `RPWM`/`LPWM` pairs, GPIO 27 as the shared driver enable, and GPIO 34/35/36/39 for encoder inputs. `w`, `s`, `a`, `d`, `x`, and `e` are recognized; unknown bytes stop output. Straight and turn commands now set wheel-speed targets for the preliminary PID implementation. The controller test and PIOArduino firmware build passed on 2026-09-04. Pin polarity, driver behavior, controller stability, and physical stop behavior still require controlled validation.

`pio run` passed on 2026-09-01. No automated tests exist. The current interface is documented in `docs/interfaces.md`.

## Inputs

- Existing firmware and `platformio.ini`.
- Two reported-purchased HiLetgo BTS7960 single-channel motor-driver modules; confirm arrival, exact board revision/datasheet, actual wiring, motor supply limits, logic levels, and whether zero duty coasts or brakes. The reported Cytron MDD10A is damaged and is not a test candidate.
- A chosen command timeout based on expected command/update rate; currently `TBD`.
- Bench equipment and a means to remove motor power independently.

## Outputs

- A small, hardware-independent command decoder/state model with automated tests.
- ESP32 integration that explicitly stops on boot, invalid/stale command, and chosen fault cases.
- Updated serial and motor interface documentation.
- Dated bench result under `results/` covering both channels and fail-safe behavior.

## Requirements

1. Outputs enter a documented safe state at boot before command processing.
2. Valid commands map deterministically to left/right direction and bounded duty.
3. Invalid input has explicitly specified behavior; line endings cannot accidentally prolong a motion lease.
4. Motion stops when no fresh valid motion command arrives within the specified timeout.
5. Stop behavior and timeout timing do not depend on blocking delays.
6. Command decoding and timeout transitions are testable without attached motors.
7. Duty bounds, GPIO ownership, polarity, and coast/brake assumptions are documented.
8. A normal serial stop must not be described as a hardware emergency stop.

## Files / Components Involved

- `src/main.cpp`
- New focused header/source files under `include/` or `lib/` only if inspection shows they improve testability
- `platformio.ini` and `test/` for a native or otherwise appropriate PlatformIO test environment
- `docs/interfaces.md`, `docs/testing.md`, this plan, and `results/`
- ESP32, motor driver, two motors, power supply, and independent power removal

## Implementation Steps

1. Record the actual driver, wiring, supply, safe-state behavior, and target timeout; stop if these inputs cannot be established.
2. Specify a command/state table including boot, valid motion, explicit stop, invalid byte, stale command, reset, and reconnect behavior.
3. Extract the smallest pure logic boundary needed to test decoding and timeout transitions; avoid a general protocol framework.
4. Add automated cases for every state-table row and time boundary.
5. Integrate the tested behavior into ESP32 output handling with an explicit boot stop and bounded duty.
6. Build firmware and run all tests; review changes for unsafe latching or wraparound/timing errors.
7. Perform unloaded, current-limited bench tests and record measured results.
8. Update interfaces, roadmap evidence, and this plan; move it to `completed/` only if every acceptance criterion passes.

## Automated Verification

- `pio run`
- PlatformIO test command for the test environment added by this plan (exact environment name to be chosen in implementation and recorded here)
- Review test output for decoder mapping, invalid input, timeout boundary, timer wraparound, and stop transitions

Do not add a test command to project documentation until it exists and runs in this repository.

## Hardware Verification

With wheels unloaded, a current-limited motor supply, and independent power removal within reach:

1. Record board, driver, wiring revision, supply voltage/current limit, firmware commit, and timeout.
2. Verify outputs remain stopped during boot/reset and before the first valid command.
3. Send each command and record both wheel directions, PWM behavior, and current.
4. Stop explicitly and measure/observe the resulting driver and wheel state.
5. While commanding motion, disconnect/stop serial traffic and measure time to safe state.
6. Test invalid bytes and terminal line endings without extending motion beyond the specified lease.
7. Repeat critical stop/timeout cases at least three times.
8. Save the result as `results/YYYY-MM-DD-motor-command-bench.md`.

## Acceptance Criteria

- Firmware builds and all new automated tests pass reproducibly.
- Every documented command and timeout transition has an automated assertion.
- No motion output can remain commanded indefinitely after command loss.
- Both channels pass boot, direction, explicit-stop, invalid-input, and timeout bench checks for at least three trials.
- The bench result includes measured timeout values and identifies coast/brake behavior.
- `docs/interfaces.md`, `ARCHITECTURE.md`, `ROADMAP.md`, and this plan reflect the verified state without overstating emergency-stop capability.

## Progress

- 2026-09-01 — Repository audited; firmware build passed; plan created. No feature implementation or hardware verification performed.
- 2026-09-01 — Builder reported a Cytron MDD10A, two expected 12 V 131:1 encoder gearmotors, a Tattu LiPo, Pololu wheels, an ESP32, and a printed chassis. Exact variants and electrical/mechanical details remain unverified; see the [parts list](../../../hardware/parts-list.md).
- 2026-09-03 — Builder reported purchasing two HiLetgo BTS7960 motor drivers to replace the damaged Cytron, and reported a four-channel level shifter on hand for possible encoder signal conditioning. Neither part has been electrically verified.
- 2026-09-03 — Firmware was rewritten for the planned BTS7960 and encoder GPIO map, including explicit stop-at-boot, unknown-input stop, and a 1000 ms command timeout. `pio run` could not be run because PlatformIO is not installed on the current computer. No hardware validation occurred.
- 2026-09-04 — Added automatic raw left/right encoder-count reporting every 200 ms while a movement command is active. No hardware validation occurred.
- 2026-09-04 — Builder reported that the initial mapping produced right turn for `w`, left turn for `s`, forward for `a`, and reverse for `d`. The command signs were remapped accordingly; the corrected mapping still requires a controlled repeat test.
- 2026-09-04 — Increased straight-drive `w`/`s` duty from 100 to 160 and their timeout to 5000 ms at builder request. Turns remain at duty 100 with a 1000 ms timeout. This higher-power behavior requires another raised-wheel test before floor use.
- 2026-09-04 — Builder reported the remapped `a`/`d` directions were reversed; their wheel commands were swapped. The corrected turn mapping still requires a repeat test.
- 2026-09-04 — Initial encoder-feedback wheel-speed control was implemented under plan 002. Controller checks and the full PIOArduino firmware build passed; hardware PID and stop validation remain pending.

## Decisions

- Keep this plan focused on physical boot, stop, invalid-input, timeout, and power-isolation validation; closed-loop control and ROS transport are tracked separately.
- Extract only enough pure logic for deterministic tests rather than introducing a protocol framework.
- Low-level loss-of-command handling belongs on the ESP32; see [decision 001](../../decisions/001-low-level-high-level-responsibility-split.md).

## Problems / Blockers

- The intended motor drivers are two reported-purchased HiLetgo BTS7960 modules, but their arrival, exact revision, wiring, power limits, safe-state electrical behavior, and motor polarity are not recorded or verified.
- The command timeout value cannot be finalized until the expected command source/update rate is chosen.

These block physical completion, but do not block drafting the state table or testable logic with explicitly provisional parameters.

## Results

- Automated baseline: `pio run` passed on 2026-09-01.
- Preliminary motion/PID observations exist under `results/`, but the repeated safety acceptance result required by this plan does not.

## Follow-up Work

- Encoder electrical bring-up and count/sign validation.
- Closed-loop per-wheel velocity control.
- Versioned ROS-computer transport and `cmd_vel` bridge.
- Independent hardware emergency-stop/power-isolation design.

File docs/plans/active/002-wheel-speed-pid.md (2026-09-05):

# Encoder-feedback wheel-speed PID

**Status:** Active
**Owner:** Builder with Codex implementation support
**Created:** 2026-09-04
**Updated:** 2026-09-04
**Related roadmap milestone:** Implement and test wheel-speed PID

## Goal

Replace direct keyboard-to-PWM control with one fixed-rate encoder-feedback wheel-speed controller per motor while preserving the existing keyboard bring-up interface and command-loss stop behavior.

## Current State

The ESP32 reads both quadrature encoders and drives two BTS7960 modules. Builder-supplied observations show stable forward and reverse encoder changes, but counts per wheel revolution and final controller gains remain unverified.

## Inputs

- Forward ground observation at PWM 160: approximately 3440 left and 3290 right counts/s.
- Reverse raised-wheel observation at PWM 160: approximately -3280 counts/s on both wheels.
- Intended first straight target: 3000 counts/s.
- Existing GPIO map and 115200-baud keyboard interface.

## Outputs

- Testable wheel-speed controller logic.
- Two ESP32 wheel-speed control loops with telemetry.
- Firmware build result and controlled tuning results.

## Requirements

1. Run both control loops at a nominal 50 Hz using actual elapsed time.
2. Derive measured speed from encoder-count change without assuming unverified counts per revolution.
3. Limit controller output to the 8-bit PWM range.
4. Prevent integral accumulation beyond an explicit bound.
5. Reset controller state on stop and target-direction changes.
6. Preserve stop-at-boot, unknown-input stop, and command timeouts.
7. Report target speed, measured speed, controller output, and raw counts.
8. Ramp straight-drive targets up and down over 300 ms and turn targets over 100 ms while preserving immediate safety stops.

## Files / Components Involved

- `include/wheel_speed_controller.h`
- `test/wheel_speed_controller_test.cpp`
- `src/main.cpp`
- `docs/interfaces.md`
- `results/`

## Implementation Steps

1. Record the supplied encoder observations without treating them as an acceptance test.
2. Add bounded controller logic and focused automated checks.
3. Replace direct PWM commands with signed counts-per-second targets.
4. Build firmware and run controller checks.
5. Tune on raised wheels, then under controlled floor load.

## Automated Verification

- Compile and run `test/wheel_speed_controller_test.cpp` with the local C++ compiler.
- Run PIOArduino firmware build using the installed PlatformIO environment.

## Hardware Verification

With wheels raised first, command forward and reverse and inspect target, measured speed, output, and count signs. Then tune straight motion on the ground using repeated short runs with an accessible power disconnect. Record gains and repeated measured results.

## Acceptance Criteria

- Automated controller checks and firmware build pass.
- Both measured speeds converge without sustained oscillation during raised-wheel tests.
- Three ground trials show both wheels tracking the same straight target within a predefined tolerance.
- Stop and timeout behavior still pass after PID integration.

## Progress

- 2026-09-04 — Plan created from builder-supplied forward and reverse encoder observations; implementation started.
- 2026-09-04 — Added two 50 Hz wheel controllers, counts/s targets, PWM limiting, anti-windup, target-change reset, timeouts, and controller telemetry.
- 2026-09-04 — Standalone controller checks and the full PIOArduino ESP32 build passed. Hardware tuning remains pending.
- 2026-09-04 — Added a 7500 counts/s² target slew limit. Straight commands ramp up over 400 ms and begin ramping down 400 ms before their five-second timeout; explicit and safety stops remain immediate.
- 2026-09-04 — Raised-wheel `w`/`s` telemetry passed the convergence criterion at +/-3000 counts/s with no sustained oscillation. Ground-load tuning and measured stop validation remain pending.
- 2026-09-04 — Revised straight ramps from 400 ms to 300 ms and added 100 ms acceleration/deceleration ramps to turns. The controller test and full ESP32 firmware build passed; this revision still requires a new raised-wheel check.

## Decisions

- Control in encoder counts per second until counts per wheel revolution are physically measured.
- Begin with feed-forward plus PI; derivative gain starts at zero to avoid amplifying raw encoder-speed noise.

## Problems / Blockers

- Final gains require physical tuning.
- Counts per wheel revolution remain unmeasured, so rad/s conversion is deferred.

## Results

- Diagnostic observation: [`../../../results/2026-09-04-open-loop-encoder-observation.md`](../../../results/2026-09-04-open-loop-encoder-observation.md)
- Raised-wheel tracking: [`../../../results/2026-09-04-raised-wheel-pid-tracking.md`](../../../results/2026-09-04-raised-wheel-pid-tracking.md)
- Automated controller test: passed locally on 2026-09-04.
- PIOArduino `esp32dev` firmware build: passed locally on 2026-09-04.

## Follow-up Work

- Convert the interface from counts/s to rad/s after encoder resolution is measured.
- Add the versioned ROS-computer transport only after PID acceptance.

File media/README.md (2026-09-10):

# Physical mapping and autonomous path planning

The [README demo](../README.md#demo) presents these assets in workflow order:

| Artifact | File |
|---|---|
| Physical robot during teleoperated mapping | [Robot photograph](real-room/teleoperation-robot.jpg) |
| Room map displayed in RViz | [Map photograph](real-room/teleoperation-slam-map.jpg) |
| Robot navigating the room with Nav2 | [Physical recording](real-room/nav2-robot.mp4) |
| RViz view during navigation | [RViz recording](real-room/nav2-rviz.mp4) |

The photographs show manual driving with automatic SLAM map building. The videos
show autonomous path planning and navigation on the saved map, with destinations
selected by the operator. Clickable poster frames link to each full-length MP4.
Original input files remain unchanged outside Git.

[Setup, provenance and observations](../results/2026-09-10-real-room-mapping-navigation.md).

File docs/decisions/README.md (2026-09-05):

# Architecture decision records

Use a decision record when a durable technical choice affects component ownership, safety, interfaces, dependencies, or multiple future tasks. Do not create records merely to fill this directory.

Current records:

- [001: Separate low-level control from ROS autonomy](001-low-level-high-level-responsibility-split.md)
- [002: Use ros2_control on the Pi and a serial-controlled ESP32](002-ros-control-serial-boundary.md)
- [003: Keep keyboard and ROS-serial firmware as separate selectable builds](003-selectable-firmware-entry-points.md)

Name records `NNN-short-title.md` using the next available number. Include:

```md
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

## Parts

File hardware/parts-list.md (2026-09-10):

# Hardware inventory

Updated September 10, 2026. The assembled prototype is shown in the
[physical demonstration](../results/2026-09-10-real-room-mapping-navigation.md).
Component identities and dimensions below are builder-reported unless noted;
initial operation does not establish electrical ratings or calibrated accuracy.

## Components

| Component | Role and recorded status |
|---|---|
| Raspberry Pi 5, 8 GB | ROS 2 Jazzy on Ubuntu 24.04 ARM64; used in physical mapping/navigation. Purchased as a CanaKit 128 GB kit; storage model remains unrecorded. |
| ESP32 development board | Encoder sampling and wheel-speed control; PlatformIO target `esp32dev`. Exact board variant is TBD. |
| Two encoder gearmotors | Reported 12 V, 131:1, 83 RPM, 45 kg·cm; exact model and rated/stall currents are TBD. Both directions have operated. |
| Two BTS7960 driver modules | One per motor; used in recorded motion and tracking tests. Exact board revision, continuous-current and thermal limits are unverified. |
| Four-channel level shifter | Reported BSS138-style module on encoder signals. Counts observed; voltage levels and edge quality require measurement. |
| RPLIDAR A1M8 | Mounted 360-degree scanner; physical demonstration used GPIO UART at 115200 baud and observed `/scan` near 6.7 Hz. |
| Drive wheels and caster | Reported Pololu wheels on a custom printed chassis; exact wheel/hub and caster models are TBD. |
| Printed chassis and mounts | [STEP assembly and STL parts](cad/README.md) include chassis, caster mount, LiDAR holder and pillars. Printed revision/material are unrecorded. |
| Tattu LiPo battery | Reported on hand; model, cell count, capacity and compatibility remain TBD. The September 10 demonstration uses tethered power. |

The former Cytron MDD10A driver was reported damaged and is retired.

## Preliminary geometry and calibration

| Parameter | Value | Basis |
|---|---:|---|
| Wheel radius | 0.040 m | Builder-reported; loaded radius uncalibrated |
| Wheel-center separation | 0.205 m | Updated after motor relocation; replaces the earlier 0.233 m value |
| Outside tire width | 0.215 m | Builder-reported |
| Axle to front / rear | 0.180 / 0.080 m | Builder-reported |
| Individual tire width | 0.010 m | Inferred for identical tires |
| Chassis underside clearance | 0.040 m | Modeling assumption |
| LiDAR scan plane | x=0, y=0, z=0.10 m, yaw=0 | Preliminary mount relative to floor-level axle midpoint |
| Encoder resolution | 4185 counts/revolution per wheel | Approximate 41850 counts over ten rotations; formal calibration pending |
| Robot mass | 1.6 kg | Simulation assumption; final assembly not weighed |

The front faces the caster. Geometry lives in the ROS package's
`description/dimensions.xacro`; firmware and host conversion constants must agree.
Simulation mass, inertia and contact properties are estimates, not measured specifications.

## Measurements still needed

- Final loaded dimensions, LiDAR offsets and repeatable encoder calibration.
- Battery and regulator ratings, motor stall current, fuse sizing and power distribution.
- Wiring diagram with GPIOs, signal levels, common grounds and connector ratings.
- Driver enable polarity, braking/coasting behavior and measured independent power removal.

[Interface and pin assignments](../docs/interfaces.md) · [Physical test procedures](../docs/testing.md) · [Dated results](../results/README.md)

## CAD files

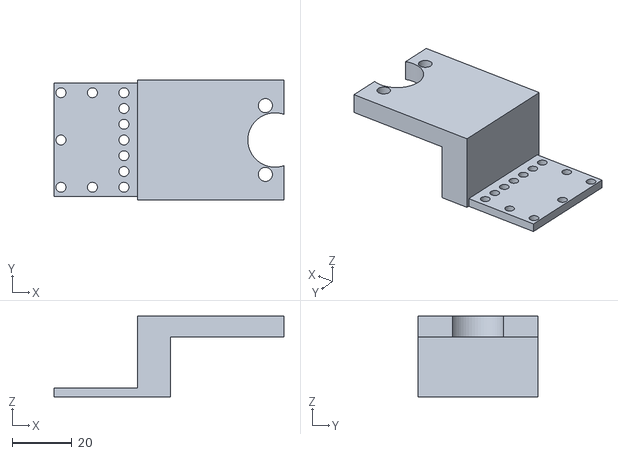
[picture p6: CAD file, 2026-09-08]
hardware/cad/caster_mount.stl
76.9 x 40.0 x 27.0

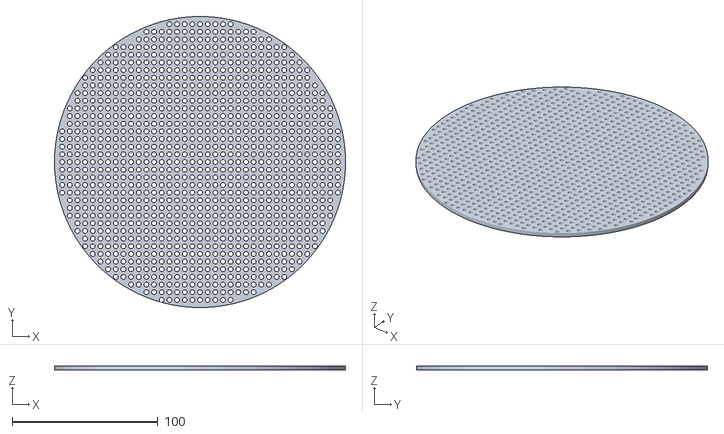
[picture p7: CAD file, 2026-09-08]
hardware/cad/chassis.stl
200.0 x 200.0 x 3.00

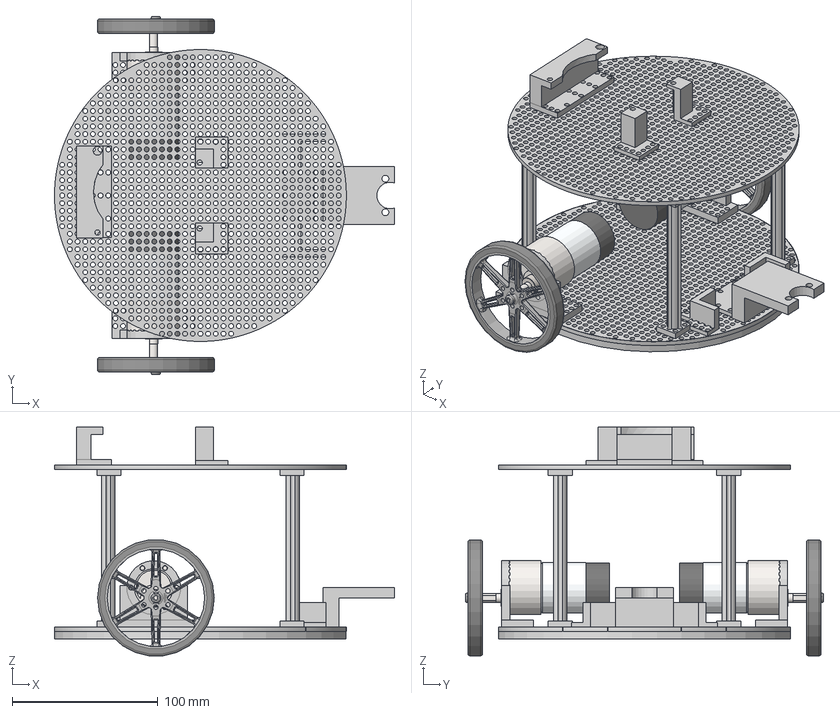
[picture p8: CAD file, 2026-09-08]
hardware/cad/autonomous_SLAM_robot_cad.step
233.0 x 245.4 x 156.7 mm
dfrobot GB37Y3530-131EN 83RPM 45Kgcm
pololu-wheel-80×10mm-black

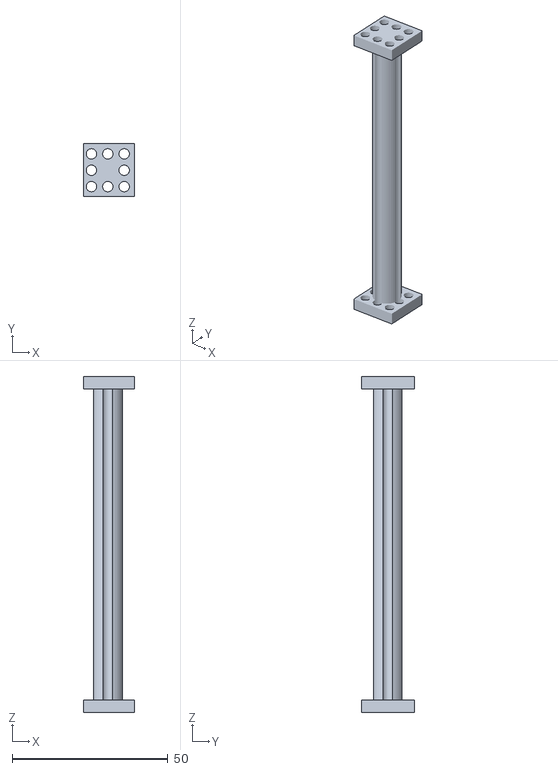
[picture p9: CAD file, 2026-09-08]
hardware/cad/PILLAR.stl
16.4 x 16.9 x 108.0

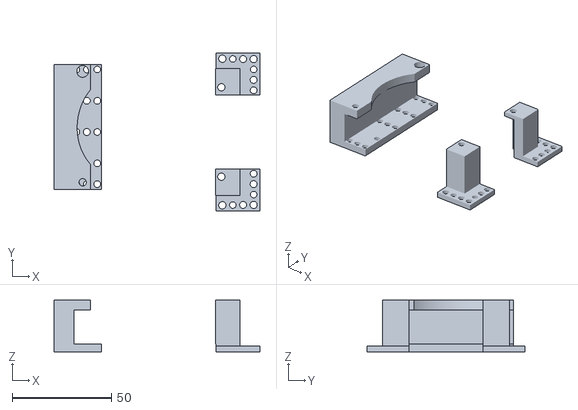
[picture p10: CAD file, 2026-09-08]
hardware/cad/Lidar_Holder.stl
104.0 x 80.0 x 26.0

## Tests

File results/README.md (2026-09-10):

# Recorded results

These records distinguish software checks, observed demonstrations and measured
hardware tests. Each report describes its setup, observations and limits.

| Date | Record |
|---|---|
| September 10, 2026 | [Physical room mapping and saved-map Nav2 demonstration](2026-09-10-real-room-mapping-navigation.md) |
| September 9, 2026 | [Initial Pi teleoperation observations](2026-09-09-pi-teleop.md) |
| September 9, 2026 | [Offline exploration checks — historical scope](2026-09-09-exploration-offline.md) |
| September 8, 2026 | [Interactive simulated LiDAR SLAM](2026-09-08-simulated-lidar-slam.md) |
| September 7, 2026 | [Initial Gazebo simulation](2026-09-07-initial-simulation.md) |
| September 7, 2026 | [ROS code audit](../ros_ws/src/my_bot/docs/results/2026-09-07-code-audit.md) |
| September 4, 2026 | [Raised-wheel feedback tracking](2026-09-04-raised-wheel-pid-tracking.md) |
| September 4, 2026 | [Ground straight-drive observation](2026-09-04-ground-straight-observation.md) |
| September 4, 2026 | [Open-loop encoder observation](2026-09-04-open-loop-encoder-observation.md) |

## Recording a new test

Use `YYYY-MM-DD-short-test-name.md`, with associated media/logs in a same-named
directory. Include date, operator, source revision, configuration, test level,
procedure, observations with units, outcome and anomalies. State pass/fail only
against criteria defined before the run. Link the record from its execution plan
and update project status when the evidence changes.

See [testing](../docs/testing.md) for automated commands and physical measurements.

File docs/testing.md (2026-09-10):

# Verification strategy

Verification has distinct levels. Always report the highest level actually completed:

1. **Build:** code compiles for its target.
2. **Automated test:** repeatable checks assert behavior without the robot.
3. **Bench test:** powered hardware is tested with wheels unloaded or subsystem isolated.
4. **Robot test:** the assembled robot performs a measured test in a controlled space.
5. **Integrated validation:** repeated mission-level trials meet predefined thresholds.

## Automated / Codex-verifiable

### Current checks

Run from the repository root:

```sh
pio run -e keyboard -e ros_serial
```

Both firmware entry points share the wheel controller. Native tests cover controller
logic, encoder arithmetic and serial parsing. The ROS package adds transport,
model and launch/configuration checks. No CI workflow is configured.

For ROS changes, run the applicable package-scoped or workspace commands:

```sh
cd ros_ws
colcon build --packages-select my_bot
colcon test --packages-select my_bot
colcon test-result --verbose
```

Record command, environment, and exact result in the execution plan. A successful build is not a test pass.

## Physical robot / human-verifiable

Physical work must begin with a test-specific hazard review, stable supports where appropriate, independent power removal within reach, and conservative power/current limits.

| Area | Example measurement/evidence |
|---|---|
| Motor bring-up | Board/driver IDs, wiring revision, unloaded wheel direction per command, stop behavior, current draw, faults |
| Command safety | Stop at boot, loss-of-command timeout, invalid input, reconnect, reset, and independent power-cut behavior |
| Encoders | Counts per wheel revolution in both directions, missed counts, sign convention, sample-rate stability |
| Straight drive | Commanded/measured distance, lateral error, duration, surface, battery condition, repeated trials |
| Rotation | Commanded/measured angle, center displacement, repeated trials |
| Odometry | Position/yaw error over named paths and time; raw and derived logs |
| LiDAR | Mount/alignment, scan orientation, obstruction, range sanity, stationary repeatability |
| SLAM | Environment, bag/config/commit, loop closure, distortion, repeatability, map assessment |
| Navigation | Goal set, success rate, path error, obstacle/recovery behavior, stopping clearance |
| Emergency behavior | Trigger mechanism, stop distance/time, actuator state, recovery requirements |
| Docking | Start poses, success rate, alignment error, charge transition, failure safety |

Thresholds must be chosen in the plan before testing; do not retrofit acceptance criteria to observations.

## Recording results

Store each run in `results/YYYY-MM-DD-short-test-name.md`; add linked logs, bags, plots, photos, or CSV files in `results/YYYY-MM-DD-short-test-name/` if needed. Follow [`results/README.md`](../results/README.md).

Every result must include:

- date, author/operator, Git commit, hardware/config revisions, environment, and test level;
- goal, preconditions/safety setup, procedure, raw observations/measurements, and units;
- explicit pass/fail against predeclared criteria;
- anomalies and follow-up work.

Unrecorded physical observations may guide investigation but do not advance the roadmap.

## Native firmware tests

From the repository root, compile and run each standalone test:

```sh
for name in encoder_count_math ros_serial_protocol wheel_speed_controller; do
  clang++ -std=c++11 -Wall -Wextra -Werror -Iinclude "test/${name}_test.cpp" -o "/tmp/${name}_test"
  "/tmp/${name}_test"
done
```

These cover parsing/conversion and controller logic, not live USB timing or ROS.
The [physical demonstration](../results/2026-09-10-real-room-mapping-navigation.md)
is separate evidence; it does not measure protocol fault-response timing.

## ROS package checks

From `ros_ws/src/my_bot`, follow [VALIDATION.md](../ros_ws/src/my_bot/VALIDATION.md)
for native serial/conformance checks. Use a Python environment with pytest, Xacro, PyYAML, NumPy and SciPy:

```sh
python3 -m pytest test/ -q
```

ROS-dependent compilation and plugin loading require Ubuntu/ROS; native tests
cannot substitute for `colcon build`, `colcon test` and physical acceptance.

## Nav2 checks — September 8, 2026

`test/test_navigation.py` under the ROS package adds command-type/limit, collision
bounds, live-map and dependency checks. Its ROS-only check generates both launches,
checks server executables and verifies clock rewrites; it is skipped without ROS.
The existing colcon test command runs it automatically. See plan 008 for required
runtime goal, cancellation, blocked-goal and repeatability checks; offline success
does not establish obstacle avoidance.

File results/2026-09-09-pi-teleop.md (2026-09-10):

# Initial Pi/ESP32 observations and latched teleop checks

Date: 2026-09-09. Operator: user, observations via chat/screenshots.
Environment: Pi 5, Ubuntu 24.04 ARM64, ROS Jazzy, ESP32 ROS serial v2,
CP2102 USB UART. Exact flashed/installed revisions and support/power setup were
not independently captured. Local source baseline e1c1564 plus latched teleop edits.

## Observations (not full acceptance)

- Initial USB enumeration failed with -71; a different connection enumerated.
- Initial ROS startup lacked a fresh stop ACK. CRC-checked telemetry and a
  stop-only Python probe later succeeded. Root cause of initial failure unresolved.
- Later controller responses showed both controllers active. User reported encoder
  position changed with hand rotation; per-wheel direction/calibration not recorded.
- Hold-to-run WASD reportedly twitched even at 0.10 m/s. A two-second continuously
  published 0.10 m/s command with subsequent zero commands reportedly worked properly.
  This supports investigating keyboard repeat; it does not prove the root cause.

## Change and automated verification

Opt-in latched Python teleop; no firmware or control/watchdog limit changes.
`python3 ros_ws/src/my_bot/test/test_teleop.py`: 5 tests passed on macOS, covering
existing expiry and new persistence/direction/stop/restart behavior. Colcon is not
installed locally. Runtime launch, X/Space/exit stopping and transport loss tests
for latched mode remain pending. No measured stop time, wheel speed or distance.

No integrated hardware acceptance is claimed. Record revision-pinned tests, all
wheel directions, stop response, disconnect/watchdog trials before ground driving.

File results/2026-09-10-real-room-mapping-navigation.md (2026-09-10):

# Real-room teleoperated SLAM and saved-map Nav2 demonstration

**Date:** September 10, 2026 (media supplied and reviewed).

**Operator:** Adrith, user-reported physical operation.

**Git commit:** Running Pi/ESP32 revisions were not captured; the documentation commit does not identify the tested binaries.

**Test level:** Integrated physical demonstration, reviewed retrospectively.

**Hardware revision:** Assembled differential-drive prototype; exact CAD/electronics revisions not recorded.

**Configuration:** Raspberry Pi 5, Ubuntu 24.04 ARM64 / ROS 2 Jazzy, ESP32 serial wheel control, mounted RPLIDAR A1M8, SLAM Toolbox, Nav2 and RViz. Physical dimensions were reported to match simulation; independent measurement was not supplied.

## Goal and acceptance criteria

Document initial manual mapping followed by navigation using the saved map.
There was no revision-pinned acceptance protocol or instrumented trial series.
These artifacts document operation; they do not establish quantitative accuracy or reliability.

## Safety setup and environment

A furnished indoor office with hard flooring. The physical photograph and video
show a trailing power cable: this is a tethered demonstration, not an untethered
power-system test. Independent emergency-stop, watchdog, disconnect and power
measurements were not recorded in these assets.

## Procedure reported by the operator

1. Bring up the Pi/ESP32 hardware interface, wheel odometry and robot transforms.
2. Run the A1M8 driver over GPIO UART (`/dev/ttyAMA0`, 115200 baud).
3. Drive using keyboard teleoperation while SLAM Toolbox builds the room map.
4. Save the map with Nav2's map saver.
5. Load the saved map with map server and AMCL, set an initial pose in RViz, and
   use Nav2 for navigation to selected destinations. This mode uses localization
   against the existing map instead of starting a fresh SLAM map.

## Measurements and observations

- The supplied photos show the physical robot in the room and an RViz occupancy
  map with room boundaries, robot representation and laser returns.
- Earlier terminal evidence in the same session shows `/scan` at approximately
  **6.707 Hz**. This is a topic-rate observation, not a LiDAR accuracy test.
- Map-saver output reports **101 × 105 cells at 0.05 m/cell**, saved successfully
  to `/home/adrithk/maps/room_20260910_130718.yaml` and `.pgm`. Grid dimensions are
  not measured room dimensions or a coverage percentage. Those files have not
  been supplied to this repository.
- `IMG_7716.mov` (49.41 seconds) shows the physical robot changing position and
  heading in the room; the power cable remains visible.
- `IMG_8248.mov` (50.67 seconds) shows RViz with a room map, laser returns and a
  robot representation changing position. The clips provide physical and display
  perspectives; no frame-accurate synchronization is claimed.
- The operator identifies the recordings as Nav2 operation. Video alone does
  not expose action results, command ownership, planner settings or arrival error.

## Result and limitations

**Initial demonstration recorded.** The operator reports successful teleoperated
mapping and Nav2 navigation. The media visually supports room-map display and
physical movement. This is autonomous path planning and navigation: the operator
selects the destination, while Nav2 plans and executes movement.

The clips do not establish complete-room coverage, a repeated success rate or
measured odometry accuracy. Earlier startup/teleop issues in the session are not
claimed resolved by a measured regression test. Physical fault handling was not
measured in these recordings.

## Artifacts and processing

- [Robot during teleoperated mapping](../media/real-room/teleoperation-robot.jpg)
- [Physical-room SLAM map in RViz](../media/real-room/teleoperation-slam-map.jpg)
- [Physical Nav2 recording](../media/real-room/nav2-robot.mp4), from `IMG_7716.mov`
- [RViz navigation recording](../media/real-room/nav2-rviz.mp4), from `IMG_8248.mov`

Photographs are copied unchanged. Videos retain full duration and playback speed
as portrait H.264 MP4 copies. The physical recording's HDR video is converted to
SDR and its standard audio track retained as AAC; the RViz recording has no audio
track. The 4K RViz source is reduced to 720 pixels wide. Container metadata and
auxiliary phone data tracks are omitted. Poster images are extracted video frames.
Original MOV files are retained outside Git and unchanged.

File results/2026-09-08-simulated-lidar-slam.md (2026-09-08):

# Initial implementation of simulated LiDAR SLAM

**Evidence supplied:** September 8, 2026  
**Operator/source:** Project owner  
**Test level:** User-supplied simulation screenshot  
**Capture date / running Git revision:** Not recorded

Gazebo and RViz simulated LiDAR SLAM

**Left:** Gazebo shows the simulated robot and obstacles. **Right:** RViz displays the initial 2D occupancy map built with SLAM Toolbox from simulated LiDAR scans. Gray-green regions are unknown/unmapped, light gray regions are observed free space, and black cells mark detected occupied surfaces such as walls and obstacles. Red points overlay the current LiDAR returns. Areas hidden behind obstacles remain unmapped until observed from another viewpoint.

The screenshot documents initial occupancy-map visualization alongside the Gazebo
simulation; RViz shows Global Status: Ok. It does not establish complete room
coverage, loop-closure accuracy, successful map export, autonomous navigation, or
physical robot validation. Those acceptance checks remain in
[plan 005](../docs/plans/active/005-simulation-slam.md).

The original screenshot is preserved unchanged; source/copy SHA-256 checks matched.

## User confirmation in chat — September 8

The operator explicitly confirmed Gazebo and RViz opened, WASD moved the robot,
and the map updated while driving. This supports a successful interactive WSL
simulation SLAM run. Exact running revision and test output were not supplied.
The earlier RViz issue did not prevent this reported run; its root cause remains
undetermined. Map export, full coverage and physical validation remain pending.
This confirmation precedes the smaller-room revision below.

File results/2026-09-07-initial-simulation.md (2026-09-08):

# Initial simulation implementation

**Date:** 2026-09-07
**Operator:** Adrith
**Test level:** User-observed WSL simulation smoke test, not a physical test
**ROS source revision:** Expected my_bot `421c7fd`; PC hash not captured.

The builder reported successful Gazebo/RViz launch, WASD movement and /scan at
10 Hz. The supplied photo shows the robot in Gazebo and red laser returns in RViz,
with Fixed Frame odom and LaserScan status Ok. This establishes the initial
simulation implementation, not a SLAM map or real ESP32/Pi integration.

The full procedure, limitations, earlier startup anomaly, and unchanged original
photo are preserved in the imported ROS package’s [simulation result](../ros_ws/src/my_bot/docs/results/2026-09-07-initial-simulation.md).

Result: pass for the observed initial simulation scope. Physical drivetrain,
serial watchdog/reconnect acceptance, measured odometry, SLAM/Nav2 and autonomous
mapping remain unverified. See active plan 004 for remaining acceptance.

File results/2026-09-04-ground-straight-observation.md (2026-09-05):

# Ground straight-drive observation

**Date:** 2026-09-04
**Operator:** Builder
**Git commit:** `504b7f9` or later working firmware; exact flashed revision not recorded
**Test level:** Diagnostic robot observation; not an acceptance test
**Hardware revision:** Current assembled differential-drive base
**Configuration:** Ground `w` command; surface, distance, payload, battery voltage, and ramp revision not recorded

## Goal

Capture the builder's qualitative report of ground straight-line behavior for future
payload tuning.

## Acceptance criteria

No quantitative threshold or procedure was declared before the observation.

## Safety setup

Not recorded.

## Environment and equipment

Not recorded.

## Procedure

The builder commanded forward motion with `w` on the ground and visually assessed
the path.

## Measurements and observations

The robot was reported to drive nearly straight while turning very slightly to the
right. No distance, lateral displacement, encoder telemetry, surface, battery state,
or final payload was recorded. The Raspberry Pi and LiDAR were not installed.

## Result

**Inconclusive.** The observation suggests usable preliminary ground behavior but
cannot close the PID acceptance criteria. No gain adjustment is justified from this
single qualitative run, especially before final payload installation.

## Anomalies

Very slight rightward drift.

## Artifacts

Builder report in the project conversation; no separate log or video.

## Follow-up

After the Raspberry Pi and LiDAR are securely mounted, perform three measured
straight runs over a fixed distance and record lateral error, encoder telemetry,
battery voltage, surface, and payload.

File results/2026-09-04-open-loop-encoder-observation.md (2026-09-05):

# Open-loop encoder observation

**Date:** 2026-09-04
**Operator:** Builder
**Git commit:** 5a32d38 plus uncommitted bring-up firmware
**Test level:** Diagnostic robot/bench observations; not an acceptance test
**Hardware revision:** Two reported HiLetgo BTS7960 modules and two reported DFRobot-like encoder motors
**Configuration:** PWM duty 160; raw encoder totals reported every 200 ms

## Goal

Check that both encoder counts change consistently in forward and reverse before implementing wheel-speed control.

## Acceptance criteria

No criteria were declared before these observations, so this record cannot advance an acceptance checkpoint.

## Safety setup

Forward was reported on the ground. Reverse was reported with the wheels raised. Other safety details were not recorded.

## Environment and equipment

Surface, battery voltage, robot load, and measurement instruments were not recorded.

## Procedure

The builder issued `w` for forward and `s` for reverse and supplied the serial encoder totals.

## Measurements and observations

- Forward on ground: both counts increased. The stable portion was approximately 3440 left and 3290 right counts/s, indicating the right wheel was roughly 4-5% slower at equal PWM.
- Reverse with wheels raised: both counts decreased. Across approximately five seconds, the averages were about -3280 left and -3270 right counts/s.
- Both signals appeared monotonic and stable at the 200 ms reporting interval.

## Result

Inconclusive as an acceptance test. The observations are sufficient to choose provisional controller signs and initial targets, but not final gains or encoder calibration.

## Anomalies

Forward and reverse used different load conditions, so their speeds are not directly comparable.

## Artifacts

Raw serial data was supplied in the project conversation and summarized here.

## Follow-up

Measure counts per wheel revolution and perform controlled PID tuning with recorded battery voltage and repeated trials.

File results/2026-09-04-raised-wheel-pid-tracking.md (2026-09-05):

# Raised-wheel PID tracking

**Date:** 2026-09-04
**Operator:** Builder
**Git commit:** `5a32d38` plus uncommitted PID/ramp firmware
**Test level:** Bench
**Hardware revision:** ESP32, two BTS7960 motor drivers, and two quadrature-encoder gearmotors
**Configuration:** Wheels raised; 50 Hz controller; target +/-3000 counts/s; 400 ms target ramp; `Kp=0.020`, `Ki=0.010`, `Kd=0`, feed-forward `0.048 PWM/(count/s)`; five-second command timeout

## Goal

Check forward and reverse unloaded wheel-speed tracking, ramp behavior, encoder signs, and visible timeout behavior with the preliminary controller.

## Acceptance criteria

The active PID plan required both measured speeds to converge without sustained oscillation during raised-wheel tests. Ground tracking and stop-safety acceptance are separate tests.

## Safety setup

The builder reported that the robot was tested in the air with the wheels unloaded. Battery voltage, current limiting, supports, and power-disconnect arrangement were not recorded.

## Environment and equipment

ESP32 serial telemetry at 115200 baud. Exact motor model, battery voltage, instrumentation, and mechanical support were not recorded.

## Procedure

With the wheels raised, the builder sent `w`, allowed its five-second timeout, and then sent `s`. The ESP32 reported requested speed, ramped target, encoder-measured speed, controller PWM, and accumulated encoder counts every 200 ms.

## Measurements and observations

- Forward ramp telemetry advanced from 0 to approximately 1545 counts/s and then 3000 counts/s across two reporting intervals, consistent with the configured 400 ms ramp.
- At the full +3000 counts/s target, the left wheel generally measured 3050 counts/s, occasionally 3100 counts/s. The right wheel generally measured 3000 counts/s, occasionally 3050 counts/s.
- Steady forward PWM settled near 142-144 left and 145-146 right.
- Reverse ramp telemetry advanced from 0 to approximately -1575 counts/s and then -3000 counts/s.
- At the full -3000 counts/s target, both wheels generally measured -3000 counts/s, with occasional -2950 or -3050 samples.
- Steady reverse PWM settled near -146 on both wheels.
- Before each timeout, the requested command changed to zero and the ramped target reached approximately +/-1500 counts/s at the next reported midpoint. The firmware then printed `Stopped: command timeout` at the five-second limit.
- Encoder counts increased during `w` and decreased during `s`, matching the controller convention.
- The beginning of the supplied transcript contained duplicated and malformed text. Later complete telemetry records were internally consistent; the malformed section was not used for measurements.

## Result

**Pass** for the predeclared raised-wheel convergence criterion. Both wheels converged to the requested unloaded speed without sustained oscillation in forward and reverse.

This does not establish ground-load tuning, straight-line driving, calibrated wheel speed, or a measured safe stop. The timeout message was observed, but no post-stop zero-PWM telemetry was captured.

## Anomalies

- The left forward wheel ran approximately 1.7-3.3% above target in the reported steady samples.
- The initial serial transcript was corrupted or duplicated.
- No current, voltage, wheel RPM, or counts-per-revolution measurement was captured.

## Artifacts

Raw telemetry was supplied in the project conversation. No separate log file was captured.

## Follow-up

1. Test `x` and timeout stopping with explicit post-stop PWM telemetry.
2. Perform three short controlled ground runs and record lateral drift, both measured wheel speeds, surface, battery voltage, and travel distance.
3. Measure encoder counts per output-shaft revolution before converting the controller interface to rad/s.

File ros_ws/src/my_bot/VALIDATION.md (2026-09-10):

# Verification on 2026-09-07

Historical verification snapshot. For current status and commands, see
[testing](../../../docs/testing.md) and [recorded results](../../../results/README.md).

Environment: macOS, clang++ C++17, local Python with Xacro 2.1.1/PyYAML.

Passed:
- Six test_model.py tests: frames/geometry/inertia, simulated sensor/bridge,
  real/default/sim model isolation, plugin declaration, clocks and speed limits,
  Python/XML/YAML syntax.
- Native serial transport test with -Wall -Wextra -Werror and pseudo-terminal ESP32:
  CRC and numeric bounds, partial telemetry, initial stop ACK, ACK sequence wrap,
  commands, explicit stop, retained-sequence reconnect, CRC corruption, dropped
  telemetry, stalled ACK, reboot, new status fault, host stalls and startup timeout.
- Firmware conformance harness against current autonomous-mapping-robot header:
  actual ESP32 parser accepts host C/X frames, host parser accepts firmware S frames.
- git diff --check.

To repeat native tests without ROS from this package directory:

```bash
c++ -std=c++17 -Wall -Wextra -Werror -pthread -Iinclude \
  src/serial_transport.cpp test/serial_transport_test.cpp -lutil -o /tmp/serial-test
/tmp/serial-test
python3 test/test_model.py
```

Protocol conformance against the firmware in this consolidated repository:

```bash
c++ -std=c++17 -Wall -Wextra -Werror -pthread -Iinclude \
  -I../../../include src/serial_transport.cpp \
  test/firmware_conformance.cpp -o /tmp/conformance-test
/tmp/conformance-test
```

Not run: ROS-dependent esp32_system.cpp compilation, pluginlib loading,
colcon build/test, Gazebo physics/rendering, WSL graphics, real USB/Pi or robot tests.
No ROS installation, Linux runtime or attached Pi was available. Current build commands are in [README.md](README.md#build); physical checks are
listed in [HARDWARE.md](HARDWARE.md).

## User-observed simulation result — 2026-09-07

Recorded [initial simulation implementation](docs/results/2026-09-07-initial-simulation.md) with the builder's original photo. Gazebo launch, WASD driving,
10 Hz simulated scans and RViz display were reported working. The screenshot
confirms visible scan returns with RViz status Ok. This supersedes earlier pending
statements for the initial simulation smoke test only; physical validation,
repeatable startup, odometry accuracy and SLAM remain pending.

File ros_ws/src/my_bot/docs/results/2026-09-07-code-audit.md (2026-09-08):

# Code audit — 2026-09-07

Scope: existing ESP32 firmware and my_bot description, dependencies, controllers,
launch sequencing, clocks/TF, serial protocol, teleoperation and simulation SLAM.
No new navigation, physical LiDAR driver or physical SLAM functionality was added.

## Findings and changes

- Fixed signed encoder rollover in the sibling firmware: both ISR increments and
  control-loop differences now wrap deliberately. Native boundary tests cover both
  directions. This preserves normal drive commands, gains and watchdog behavior.
- Added a ROS-dependent hardware_plugin_test to CTest. It loads my_bot/Esp32System
  using pluginlib, configures its interfaces and rejects an invalid joint layout.
  It never activates hardware or opens serial. This is necessary because Gazebo
  loads its own plugin, so successful simulation does not validate the real plugin.
- Reviewed package dependencies, plugin export, Xacro modes, controller joint names,
  radians/count conversion, limits, launch sequencing and fault handling. No further
  demonstrated runtime defect was found in those paths during this review.
- Simulation uses /clock throughout; hardware controllers use wall time. Only the
  differential-drive controller publishes odom->base_link; SLAM publishes map->odom.
  Scan frames/ranges match the model and SLAM configuration. No custom RViz shader
  exists in this repository. No speculative shader, QoS or timing changes were made.

## Verification actually performed

Mac environment: clang++, AddressSanitizer and UndefinedBehaviorSanitizer;
Python with Xacro 2.1.1 and PyYAML. All completed successfully:

- Both PlatformIO firmware builds: keyboard and ros_serial.
- Three firmware native suites: controller, serial protocol/conversion, encoder rollover.
- Host pseudo-terminal transport/fault suite and actual firmware-parser conformance.
- Eight model/configuration tests and three teleoperation tests.
- Diff whitespace checks for audit changes.

The new hardware_plugin_test has NOT been compiled or run here: this Mac has no
ROS/colcon/Linux runtime. Existing builder screenshots show an earlier Ubuntu build
and tests passed, but do not validate this new test. Run on Jazzy Ubuntu 24.04:

```bash
source /opt/ros/jazzy/setup.bash
cd ~/ros_ws
colcon build --symlink-install --packages-select my_bot
source install/setup.bash
colcon test --packages-select my_bot --event-handlers console_direct+
colcon test-result --verbose
```

## What the screenshots establish

Controllers activated, scan data and odom->laser transforms were observed, and
RViz logged receipt of a 79 x 79 map. Thus there is evidence of initial map output,
not proof of accurate mapping, loop closure, map saving or reliable startup.
Registering sensor is an informational message, not a completion progress bar.
A topic echo/rate command subscribes to /scan; it does not publish LiDAR data.

RViz reported an indexed-map shader error even with software rendering. The same
error has been reported upstream on Jazzy on a Pi 5, so it is NOT established as
WSL-only and switching computers is not a guaranteed fix. The exact local graphics
failure remains unresolved. TF queue-drop messages also need timestamp validation
if persistent; they are not proof that /scan is absent.

References checked:
- https://github.com/ros2/rviz/issues/1279
- https://github.com/ros2/rviz/pull/459
- https://control.ros.org/jazzy/doc/ros2_control/hardware_interface/doc/writing_new_hardware_component.html
- https://github.com/SteveMacenski/slam_toolbox/blob/jazzy/launch/online_async_launch.py

## Remaining real-robot acceptance

Hardware plugin load and physical USB/watchdog/reconnect tests are still required.
The physical LiDAR driver and real SLAM launch are not yet implemented. Before
adding them, confirm encoder calibration/direction, loaded dimensions and actual
laser mount, then validate odometry, live scan timestamps and TF on the Pi. Mapping
can run without RViz, but that does not establish the GUI works or the map is valid.

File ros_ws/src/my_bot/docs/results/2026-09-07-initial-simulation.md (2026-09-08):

# Initial simulation implementation

**Date:** 2026-09-07 (recorded from builder-provided evidence)
**Operator:** Adrith
**Test level:** User-observed simulation smoke test; no physical robot test
**Source revision:** Expected my_bot main at `421c7fd` (WASD implementation);
exact PC checkout hash was not captured.
**Environment:** Windows PC, WSL, ROS 2 Jazzy, Gazebo Sim and RViz.
Exact Ubuntu release, GPU/driver and installed package versions were not captured.
**Physical hardware:** No Pi, ESP32 or physical LiDAR required/connected for this test.

## Goal and existing checks

Exercise initial simulation bringup, keyboard movement and simulated laser display,
as listed in SIMULATION.md's first-run checks. This record covers those observed
checks only; it does not establish every simulation or real-hardware acceptance criterion.

## Procedure

1. Builder cloned/built the my_bot package in `/home/adrith/ros_ws`.
2. Builder supplied an earlier terminal photo showing all three CTest entries
   passing and colcon reporting 12 tests, zero errors/failures/skips.
3. Sourced Jazzy and the workspace; launched `ros2 launch my_bot bringup.launch.py`.
4. Started `ros2 run my_bot teleop_wasd --ros-args -p use_sim_time:=true
   -r cmd_vel:=/diff_drive_controller/cmd_vel` in a separate terminal.
5. Builder reported successful movement using WASD, then reported `/scan` at 10 Hz.
6. Added the Views panel and selected TopDownOrtho to make the full scan visible.

## Observations and evidence

- Gazebo displays mapping_robot in the test room with walls and an obstacle.
- RViz displays red simulated laser returns outlining room boundaries.
- Visible RViz settings: Fixed Frame `odom`, LaserScan topic `/scan`, Status `Ok`,
  Best Effort reliability, Volatile durability, Flat Squares, size 0.04 m.
- The Views panel shows TopDownOrtho and Scale 100 in the attached photo.
- Builder confirmed WASD driving worked. Movement and 10 Hz frequency are reported
  observations; the still photo itself does not measure motion or scan frequency.
- These dots are laser returns, not a SLAM occupancy map. No saved map, SLAM Toolbox,
  Nav2 mission or autonomous exploration was demonstrated.

## Result

**Pass for initial simulation smoke-test scope:** launch, user-reported teleoperation,
user-reported scan publication and visible RViz laser display.
Real motor control, odometry accuracy and robust repeated startup remain unverified.

## Anomalies and recovery

- Initial package discovery failed because a shell command escaped the home-directory
  tilde. Sourcing the workspace with its full path resolved discovery.
- A later launch showed joint_state_broadcaster spawner exit 1, triggering coordinated
  shutdown. The originating error was not captured. A clean WSL restart was suggested;
  subsequent successful operation was reported, but exact recovery steps were not recorded.
- RViz camera manipulation was confusing; adding the Views panel and selecting
  TopDownOrtho resolved the builder's display problem.
- Prior failed command output remains visible behind the working applications in
  the photo; it is not evidence that every previous launch succeeded.

## Artifact

Original builder-supplied photo, preserved without modification:

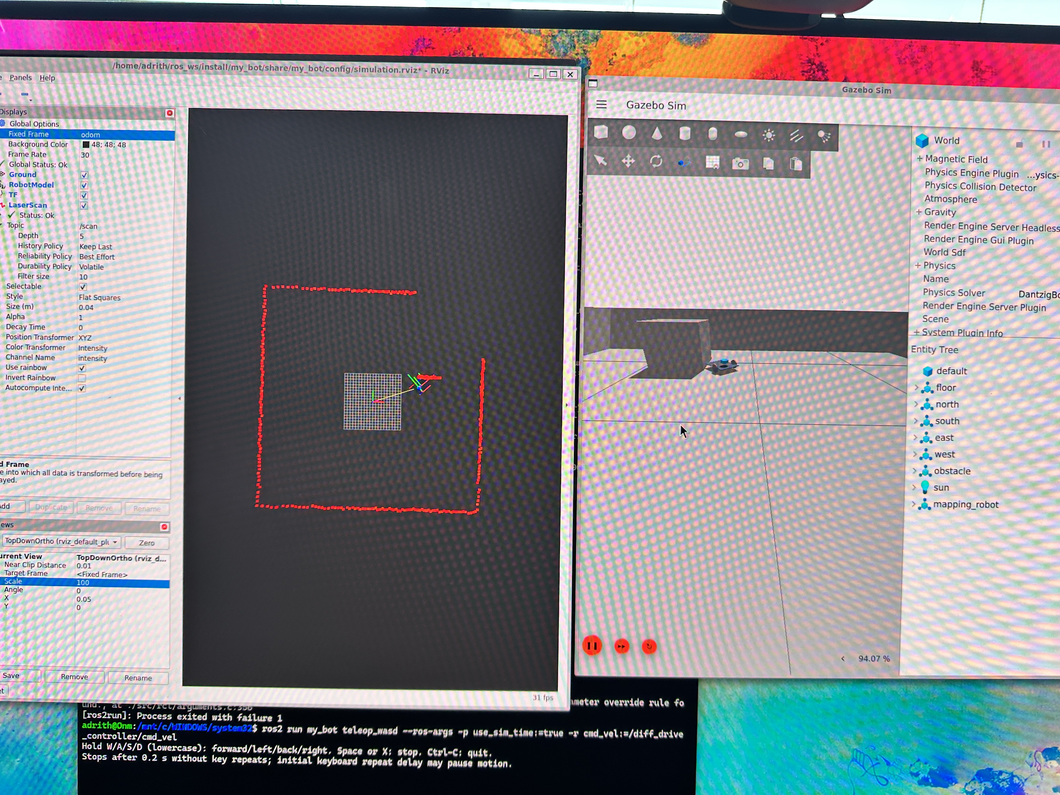
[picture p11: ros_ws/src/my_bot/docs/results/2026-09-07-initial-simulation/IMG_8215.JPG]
Initial Gazebo simulation with RViz laser returns


## Follow-up

Capture exact Ubuntu/package versions and checkout hash; verify repeatable startup,
controller activity, odometry signs and stop behavior. Save the preferred RViz layout.
Next integrate SLAM Toolbox with simulated /scan and odometry; physical Pi/ESP32/LiDAR
bringup remains a separate validation task.

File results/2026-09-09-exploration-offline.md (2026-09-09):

# Exploration implementation: offline evidence only

Setup: macOS development workspace; temporary Python environment with xacro,
PyYAML, NumPy 2.5.3 and SciPy 1.18.1. No physical robot attached. No ROS/Jazzy,
colcon or Gazebo available on this host.

Command:

```bash
/tmp/my-bot-urdf-venv/bin/python -m unittest discover -s ros_ws/src/my_bot/test -p 'test_*.py'
```

Outcome: 30 passed; 12 skipped because ROS is unavailable. The ray-visibility
fixture required multiple safe viewpoints and revealed over 500 cells behind its
partition. This fixture contains no ROS actions, physics or SLAM and must not be
reported as a successful robot simulation mission. ROS adapter failure tests are
present but require target execution. Source/launch Python, XML and 38 Bash blocks
parsed successfully; git diff whitespace check passed.

Informational microcheck: 50 frontier searches of a 200x200 synthetic grid averaged
1.96 ms/search on this Mac, returning 9 candidates. No Pi speedup is established.

`colcon build --packages-select my_bot` could not run (command not found).
Still required: Jazzy package build/tests; two fresh runs of both Gazebo worlds;
no collisions; autonomous destination progression; stop/fault handling; truthful
PARTIAL for unreachable frontiers; real SaveMap service result and YAML/PGM reload.
See WSL_COPY_PASTE.md Option C. Physical deployment is not accepted by this result.

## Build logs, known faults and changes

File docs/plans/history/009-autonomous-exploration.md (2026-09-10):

# Historical implementation record — scope withdrawn September 10, 2026

The documented project now covers teleoperated mapping and autonomous path planning
to operator-selected goals. This record preserves earlier engineering work and
is not an active product plan or commitment. Existing code is unchanged.

# Autonomous closed-room exploration — September 9, 2026

Accepted: simulation-first frontier selection over live SLAM, safe known-space
viewpoints checked by Nav2, one active goal, bounded failure handling, truthful
completion/partial status, stationary confirmation and automatic map saving.
Keep firmware/manual launches unchanged. Implement an independent geometry/policy
core and a ROS adapter; expose start/stop/retry-save services and RViz markers.

Validation: geometry and mission-policy tests, mocked action failures, ROS-specific
adapter tests where Jazzy is available, build/test plus repeated runtime missions
in the original and an occluded world. Record unavailable target validation as
pending, never substitute offline tests for navigation/physical acceptance.

Implementation and results will be recorded below. This plan stays active until
runtime acceptance (collision-free autonomous goals, stop, saved map reload and
honest unreachable-area handling) is met.

## Implementation

Added pure NumPy/SciPy grid/frontier geometry, known-space footprint clearance,
multiple viewpoints, local occupancy-change-aware retries and completion/action
lease guards. ROS adapter uses standard lifecycle/action/GetCostmap/SaveMap APIs,
handles cancellation while goal acceptance is pending, checks health continuously,
distinguishes partial/fault/save failure, and verifies stationary feedback and
saved files. Stop-confirmation failure exits the explorer and shuts its launch
stack down through OnProcessExit. Save failure alone keeps SLAM alive.

Added explore_sim launch, separate RViz view/configuration, alternate occluded
world, CMake Python installation/dependencies and unit/ROS-adapter tests. Forwarded
world selection through existing wrappers without changing their default worlds.
Updated architecture/roadmap/interfaces/testing and WSL Option C. Physical speed,
firmware, manual launches and navigation obstacle checks remain unchanged.

## Verification — September 9

30 offline tests passed including deterministic synthetic occluded-view progress.
12 ROS-dependent tests (10 new adapter checks and 2 existing launch checks) cannot
run on this Mac and are skipped. Python/XML/Bash syntax and diff checks passed.
On a 200x200 synthetic occupancy grid, 50 repeated selection calls averaged about
1.96 ms on this Mac; this is not a Pi or navigation performance measurement.

Attempted colcon build: command not found. No ROS/Gazebo or configured SSH PC
connection is available here, so Jazzy build/test, repeated two-world missions,
collision-free execution, actual map save/reload and physical testing remain
pending. Exact target commands and acceptance checks are in WSL Option C.
The plan remains active; source implementation is not full mission acceptance.

Upstream Jazzy interfaces verified: ComputePathToPose, NavigateToPose, FollowPath,
SaveMap and Costmap2DPublisher/GetCostmap, plus MapSaver's service naming. In
particular FollowPath uses 100-series error codes in Jazzy; TF errors are faults,
not excluded candidates. Only documented spatial/progress errors are retried as
viewpoint failures. Existing explore_lite was inspected; all-blacklisted completion
is deliberately not used as evidence of full coverage in this mission.

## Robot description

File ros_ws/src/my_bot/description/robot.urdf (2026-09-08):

<?xml version="1.0" ?>
<!-- =================================================================================== -->
<!-- |    This document was autogenerated by xacro from /Users/adrithk/Developer/my_bot/description/robot.urdf.xacro | -->
<!-- |    EDITING THIS FILE BY HAND IS NOT RECOMMENDED                                 | -->
<!-- =================================================================================== -->
<robot name="mapping_robot">
  <material name="chassis_black">
    <color rgba="0.15 0.16 0.18 1"/>
  </material>
  <material name="tire_gray">
    <color rgba="0.35 0.36 0.38 1"/>
  </material>
  <material name="front_blue">
    <color rgba="0.1 0.5 0.9 1"/>
  </material>
  <link name="base_link"/>
  <!-- A thin rectangular approximation of the whole length, including front
       extension. Plate thickness is visual-only and unmeasured. -->
  <link name="chassis">
    <inertial>
      <origin xyz="0 0 0.03"/>
      <mass value="1.2300000000000002"/>
      <inertia ixx="0.0045535624999999995" ixy="0" ixz="0" iyy="0.007585000000000002" iyz="0" izz="0.010826562500000003"/>
    </inertial>
    <visual>
      <geometry>
        <box size="0.26 0.19499999999999998 0.005"/>
      </geometry>
      <material name="chassis_black"/>
    </visual>
    <collision>
      <geometry>
        <box size="0.26 0.19499999999999998 0.005"/>
      </geometry>
    </collision>
  </link>
  <joint name="chassis_joint" type="fixed">
    <parent link="base_link"/>
    <child link="chassis"/>
    <origin xyz="0.049999999999999996 0 0.0425"/>
  </joint>
  <link name="left_wheel">
    <inertial>
      <origin rpy="1.5707963267948966 0 0" xyz="0 0 0"/>
      <mass value="0.08"/>
      <inertia ixx="3.266666666666666e-05" ixy="0" ixz="0" iyy="3.266666666666666e-05" iyz="0" izz="6.400000000000001e-05"/>
    </inertial>
    <visual>
      <origin rpy="1.5707963267948966 0 0"/>
      <geometry>
        <cylinder length="0.010000000000000009" radius="0.04"/>
      </geometry>
      <material name="tire_gray"/>
    </visual>
    <collision>
      <origin rpy="1.5707963267948966 0 0"/>
      <geometry>
        <cylinder length="0.010000000000000009" radius="0.04"/>
      </geometry>
    </collision>
  </link>
  <joint name="left_wheel_joint" type="continuous">
    <parent link="base_link"/>
    <child link="left_wheel"/>
    <origin xyz="0 0.1025 0.04"/>
    <axis xyz="0 1 0"/>
    <limit effort="0.3" velocity="12.5"/>
  </joint>
  <link name="right_wheel">
    <inertial>
      <origin rpy="1.5707963267948966 0 0" xyz="0 0 0"/>
      <mass value="0.08"/>
      <inertia ixx="3.266666666666666e-05" ixy="0" ixz="0" iyy="3.266666666666666e-05" iyz="0" izz="6.400000000000001e-05"/>
    </inertial>
    <visual>
      <origin rpy="1.5707963267948966 0 0"/>
      <geometry>
        <cylinder length="0.010000000000000009" radius="0.04"/>
      </geometry>
      <material name="tire_gray"/>
    </visual>
    <collision>
      <origin rpy="1.5707963267948966 0 0"/>
      <geometry>
        <cylinder length="0.010000000000000009" radius="0.04"/>
      </geometry>
    </collision>
  </link>
  <joint name="right_wheel_joint" type="continuous">
    <parent link="base_link"/>
    <child link="right_wheel"/>
    <origin xyz="0 -0.1025 0.04"/>
    <axis xyz="0 1 0"/>
    <limit effort="0.3" velocity="12.5"/>
  </joint>
  <!-- Fixed sphere depicts the front support; size/position are provisional. -->
  <link name="caster">
    <inertial>
      <mass value="0.04"/>
      <inertia ixx="6.4000000000000006e-06" ixy="0" ixz="0" iyy="6.4000000000000006e-06" iyz="0" izz="6.4000000000000006e-06"/>
    </inertial>
    <visual>
      <geometry>
        <sphere radius="0.02"/>
      </geometry>
      <material name="front_blue"/>
    </visual>
    <collision>
      <geometry>
        <sphere radius="0.02"/>
      </geometry>
    </collision>
  </link>
  <joint name="caster_joint" type="fixed">
    <parent link="base_link"/>
    <child link="caster"/>
    <origin xyz="0.16 0 0.02"/>
  </joint>
  <link name="laser">
    <inertial>
      <origin rpy="0 0 0" xyz="0 0 -0.0145"/>
      <mass value="0.17"/>
      <inertia ixx="6.0916666666666686e-05" ixy="0" ixz="0" iyy="6.0916666666666686e-05" iyz="0" izz="0.00010412500000000004"/>
    </inertial>
    <visual>
      <!-- Keep the visual below the scan plane to avoid self-obstruction. -->
      <origin xyz="0 0 -0.0145"/>
      <geometry>
        <cylinder length="0.025" radius="0.035"/>
      </geometry>
      <material name="front_blue"/>
    </visual>
  </link>
  <joint name="laser_joint" type="fixed">
    <parent link="base_link"/>
    <child link="laser"/>
    <origin rpy="0 0 0.0" xyz="0.0 0.0 0.10"/>
  </joint>
</robot>

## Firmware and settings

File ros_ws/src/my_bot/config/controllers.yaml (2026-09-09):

# Simulation defaults. Geometry must match dimensions.xacro (checked by tests).
# Speed/acceleration/covariance values are estimates, not hardware acceptance limits.
controller_manager:
  ros__parameters:
    update_rate: 50
    use_sim_time: true
    joint_state_broadcaster:
      type: joint_state_broadcaster/JointStateBroadcaster
    diff_drive_controller:
      type: diff_drive_controller/DiffDriveController

diff_drive_controller:
  ros__parameters:
    use_sim_time: true
    left_wheel_names: [left_wheel_joint]
    right_wheel_names: [right_wheel_joint]
    wheel_separation: 0.205
    wheel_radius: 0.04
    position_feedback: true
    open_loop: false
    publish_rate: 50.0
    odom_frame_id: odom
    base_frame_id: base_link
    enable_odom_tf: true
    cmd_vel_timeout: 0.25
    pose_covariance_diagonal: [0.01, 0.01, 1000.0, 1000.0, 1000.0, 0.05]
    twist_covariance_diagonal: [0.01, 0.01, 1000.0, 1000.0, 1000.0, 0.05]
    linear.x.max_velocity: 0.20
    linear.x.min_velocity: -0.20
    linear.x.max_acceleration: 0.3
    linear.x.max_deceleration: -0.3
    angular.z.max_velocity: 0.75
    angular.z.min_velocity: -0.75
    angular.z.max_acceleration: 1.5
    angular.z.max_deceleration: -1.5

joint_state_broadcaster:
  ros__parameters:
    use_sim_time: true

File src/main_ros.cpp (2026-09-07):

#include <Arduino.h>

#include <cmath>

#include "robot_drive.h"
#include "ros_serial_protocol.h"
#include "ros_wheel_units.h"

namespace
{

constexpr uint32_t kCommandWatchdogMs = 250;
constexpr uint32_t kCommandRampMs = 100;
constexpr uint32_t kTelemetryIntervalMs = 50;

constexpr uint16_t kStatusCommandTimeout = 1U << 0;
constexpr uint16_t kStatusReceiveOverflow = 1U << 1;
constexpr uint16_t kStatusBadFormat = 1U << 2;
constexpr uint16_t kStatusBadChecksum = 1U << 3;
constexpr uint16_t kStatusOutOfRange = 1U << 4;
constexpr uint16_t kStatusStaleSequence = 1U << 5;

RosSerialProtocol::Parser gParser;
bool gHasAcceptedSequence = false;
uint32_t gLastAcceptedSequence = 0;
uint32_t gLastTelemetryMs = 0;
uint16_t gLatchedStatusBits = 0;

bool sequenceIsAcceptable(uint32_t sequence)
{
  return !gHasAcceptedSequence ||
         RosSerialProtocol::isNewerSequence(sequence, gLastAcceptedSequence);
}

void acceptSequence(uint32_t sequence)
{
  gHasAcceptedSequence = true;
  gLastAcceptedSequence = sequence;
}

void handleFrame(const RosSerialProtocol::CommandFrame &frame,
                 RosSerialProtocol::ParseResult result)
{
  if (!sequenceIsAcceptable(frame.sequence))
  {
    gLatchedStatusBits |= kStatusStaleSequence;
    return;
  }

  if (result == RosSerialProtocol::ParseResult::StopReady)
  {
    acceptSequence(frame.sequence);
    RobotDrive::stop();
    return;
  }

  float leftCountsPerSecond = 0.0f;
  float rightCountsPerSecond = 0.0f;
  if (!RosWheelUnits::convertCommand(frame.leftRadiansPerSecond,
                                     frame.rightRadiansPerSecond,
                                     leftCountsPerSecond, rightCountsPerSecond))
  {
    gLatchedStatusBits |= kStatusOutOfRange;
    return;
  }

  acceptSequence(frame.sequence);
  if (leftCountsPerSecond == 0 && rightCountsPerSecond == 0)
  {
    RobotDrive::stop();
    return;
  }
  RobotDrive::commandWheelSpeeds(leftCountsPerSecond,
                                 rightCountsPerSecond,
                                 kCommandWatchdogMs, kCommandRampMs);
}

void readSerialFrames()
{
  while (Serial.available() > 0)
  {
    RosSerialProtocol::CommandFrame frame{};
    const RosSerialProtocol::ParseResult result =
        gParser.push(static_cast<char>(Serial.read()), frame);
    switch (result)
    {
    case RosSerialProtocol::ParseResult::CommandReady:
    case RosSerialProtocol::ParseResult::StopReady:
      handleFrame(frame, result);
      break;
    case RosSerialProtocol::ParseResult::Overflow:
      gLatchedStatusBits |= kStatusReceiveOverflow;
      RobotDrive::stop();
      break;
    case RosSerialProtocol::ParseResult::BadFormat:
      gLatchedStatusBits |= kStatusBadFormat;
      break;
    case RosSerialProtocol::ParseResult::BadChecksum:
      gLatchedStatusBits |= kStatusBadChecksum;
      break;
    case RosSerialProtocol::ParseResult::Incomplete:
      break;
    }
  }
}

void sendTelemetry(uint32_t nowMs)
{
  const DriveTelemetry drive = RobotDrive::telemetry();
  const RosSerialProtocol::StateFrame state{
      gHasAcceptedSequence ? gLastAcceptedSequence : 0,
      nowMs,
      drive.leftEncoderCount,
      drive.rightEncoderCount,
      static_cast<int32_t>(std::lround(drive.leftMeasuredCountsPerSecond)),
      static_cast<int32_t>(std::lround(drive.rightMeasuredCountsPerSecond)),
      drive.leftControllerPwm,
      drive.rightControllerPwm,
      gLatchedStatusBits,
  };
  char frame[RosSerialProtocol::kMaximumFrameLength];
  const size_t frameLength =
      RosSerialProtocol::formatStateFrame(frame, sizeof(frame), state);
  if (frameLength > 0)
  {
    Serial.write(reinterpret_cast<const uint8_t *>(frame), frameLength);
  }
}

} // namespace

void setup()
{
  Serial.begin(115200);
  RobotDrive::begin();
  gLastTelemetryMs = millis();
}

void loop()
{
  readSerialFrames();

  const uint32_t nowMs = millis();
  if (RobotDrive::update(nowMs) == DriveUpdateEvent::CommandTimedOut)
  {
    gLatchedStatusBits |= kStatusCommandTimeout;
  }

  if (nowMs - gLastTelemetryMs >= kTelemetryIntervalMs)
  {
    gLastTelemetryMs = nowMs;
    sendTelemetry(nowMs);
  }
}

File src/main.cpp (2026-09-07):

#include <Arduino.h>

#include "robot_drive.h"

namespace
{

  constexpr uint32_t kReportIntervalMs = 200;
  constexpr uint32_t kStraightTimeoutMs = 5000;
  constexpr uint32_t kTurnTimeoutMs = 1000;
  constexpr uint32_t kStraightRampMs = 300;
  constexpr uint32_t kTurnRampMs = 100;
  constexpr float kStraightTargetCountsPerSecond = 3000.0f;
  constexpr float kTurnTargetCountsPerSecond = 1800.0f;

  uint32_t gLastReportMs = 0;

  void printTelemetry()
  {
    const DriveTelemetry state = RobotDrive::telemetry();
    Serial.printf(
        "pid left_command=%.0f left_target=%.0f left_speed=%.0f left_pwm=%d "
        "left_count=%ld right_command=%.0f right_target=%.0f right_speed=%.0f "
        "right_pwm=%d right_count=%ld\n",
        state.leftRequestedCountsPerSecond, state.leftTargetCountsPerSecond,
        state.leftMeasuredCountsPerSecond, state.leftControllerPwm,
        static_cast<long>(state.leftEncoderCount),
        state.rightRequestedCountsPerSecond, state.rightTargetCountsPerSecond,
        state.rightMeasuredCountsPerSecond, state.rightControllerPwm,
        static_cast<long>(state.rightEncoderCount));
  }

  void handleCommand(char command)
  {
    switch (command)
    {
    case 'w':
      RobotDrive::commandWheelSpeeds(kStraightTargetCountsPerSecond,
                                     kStraightTargetCountsPerSecond,
                                     kStraightTimeoutMs, kStraightRampMs);
      break;
    case 's':
      RobotDrive::commandWheelSpeeds(-kStraightTargetCountsPerSecond,
                                     -kStraightTargetCountsPerSecond,
                                     kStraightTimeoutMs, kStraightRampMs);
      break;
    case 'a':
      RobotDrive::commandWheelSpeeds(-kTurnTargetCountsPerSecond,
                                     kTurnTargetCountsPerSecond, kTurnTimeoutMs,
                                     kTurnRampMs);
      break;
    case 'd':
      RobotDrive::commandWheelSpeeds(kTurnTargetCountsPerSecond,
                                     -kTurnTargetCountsPerSecond, kTurnTimeoutMs,
                                     kTurnRampMs);
      break;
    case 'x':
      RobotDrive::stop();
      break;
    case 'e':
    {
      const DriveTelemetry state = RobotDrive::telemetry();
      Serial.printf("left_count=%ld right_count=%ld\n",
                    static_cast<long>(state.leftEncoderCount),
                    static_cast<long>(state.rightEncoderCount));
      break;
    }
    case '\r':
    case '\n':
      break;
    default:
      RobotDrive::stop();
      Serial.printf("Stopped: unknown command '%c'\n", command);
      break;
    }
  }

} // namespace

void setup()
{
  Serial.begin(115200);
  RobotDrive::begin();
  gLastReportMs = millis();

  Serial.println("ESP32 encoder-feedback wheel control ready");
  Serial.println("Commands: w/s/a/d move, x stop, e encoder counts");
  Serial.println("Straight target: 3000 counts/s for 5000 ms; ramp: 300 ms");
  Serial.println("Turn target: 1800 counts/s for 1000 ms; ramp: 100 ms");
}

void loop()
{
  while (Serial.available() > 0)
  {
    handleCommand(static_cast<char>(Serial.read()));
  }

  const uint32_t nowMs = millis();
  if (RobotDrive::update(nowMs) == DriveUpdateEvent::CommandTimedOut)
  {
    Serial.println("Stopped: command timeout");
  }

  if (RobotDrive::motionCommandActive() &&
      nowMs - gLastReportMs >= kReportIntervalMs)
  {
    gLastReportMs = nowMs;
    printTelemetry();
  }
}

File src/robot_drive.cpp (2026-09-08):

#include "robot_drive.h"

#include <cmath>

#include "wheel_speed_controller.h"
#include "encoder_count_math.h"

namespace
{

constexpr uint8_t kLeftRpwmPin = 25;
constexpr uint8_t kLeftLpwmPin = 26;
constexpr uint8_t kDriverEnablePin = 27;
constexpr uint8_t kRightRpwmPin = 32;
constexpr uint8_t kRightLpwmPin = 33;

constexpr uint8_t kLeftEncoderAPin = 34;
constexpr uint8_t kLeftEncoderBPin = 35;
constexpr uint8_t kRightEncoderAPin = 36;
constexpr uint8_t kRightEncoderBPin = 39;

constexpr uint32_t kPwmFrequencyHz = 20000;
constexpr uint8_t kPwmResolutionBits = 8;
constexpr uint32_t kControlIntervalMs = 20;
constexpr WheelSpeedControllerGains kInitialGains{
    0.020f,
    0.010f,
    0.000f,
    0.048f,
};
constexpr float kMaximumPwm = 200.0f;
constexpr float kIntegralLimit = 4000.0f;
constexpr int8_t kLeftMotorPolarity = -1;
constexpr int8_t kRightMotorPolarity = 1;

volatile int32_t gLeftEncoderCount = 0;
volatile int32_t gRightEncoderCount = 0;
portMUX_TYPE gEncoderMux = portMUX_INITIALIZER_UNLOCKED;

WheelSpeedController gLeftController(kInitialGains, kMaximumPwm, kIntegralLimit);
WheelSpeedController gRightController(kInitialGains, kMaximumPwm, kIntegralLimit);

float gLeftRequestedSpeed = 0.0f;
float gRightRequestedSpeed = 0.0f;
float gLeftTargetSpeed = 0.0f;
float gRightTargetSpeed = 0.0f;
float gLeftMeasuredSpeed = 0.0f;
float gRightMeasuredSpeed = 0.0f;
float gTargetSlewRateCountsPerSecondSquared = 0.0f;
int16_t gLeftControllerOutput = 0;
int16_t gRightControllerOutput = 0;

bool gMotionCommandActive = false;
uint32_t gLastMotionCommandMs = 0;
uint32_t gActiveCommandTimeoutMs = 0;
uint32_t gActiveRampDurationMs = 0;
uint32_t gLastControlMs = 0;
int32_t gPreviousLeftEncoderCount = 0;
int32_t gPreviousRightEncoderCount = 0;

struct EncoderCounts
{
  int32_t left;
  int32_t right;
};

EncoderCounts readEncoderCounts()
{
  EncoderCounts counts;
  portENTER_CRITICAL(&gEncoderMux);
  counts.left = gLeftEncoderCount;
  counts.right = gRightEncoderCount;
  portEXIT_CRITICAL(&gEncoderMux);
  return counts;
}

void writeMotorPwm(uint8_t forwardPin, uint8_t reversePin, int16_t signedPwm)
{
  uint16_t magnitude = signedPwm >= 0 ? signedPwm : -signedPwm;
  if (magnitude > 255)
  {
    magnitude = 255;
  }

  if (signedPwm > 0)
  {
    ledcWrite(reversePin, 0);
    ledcWrite(forwardPin, magnitude);
  }
  else if (signedPwm < 0)
  {
    ledcWrite(forwardPin, 0);
    ledcWrite(reversePin, magnitude);
  }
  else
  {
    ledcWrite(forwardPin, 0);
    ledcWrite(reversePin, 0);
  }
}

float moveToward(float current, float requested, float maximumChange)
{
  if (current < requested)
  {
    const float increased = current + maximumChange;
    return increased < requested ? increased : requested;
  }
  if (current > requested)
  {
    const float decreased = current - maximumChange;
    return decreased > requested ? decreased : requested;
  }
  return requested;
}

void IRAM_ATTR onLeftEncoderAChange()
{
  const bool encoderA = digitalRead(kLeftEncoderAPin);
  const bool encoderB = digitalRead(kLeftEncoderBPin);
  portENTER_CRITICAL_ISR(&gEncoderMux);
  gLeftEncoderCount = encoderStep(gLeftEncoderCount, encoderA == encoderB);
  portEXIT_CRITICAL_ISR(&gEncoderMux);
}

void IRAM_ATTR onRightEncoderAChange()
{
  const bool encoderA = digitalRead(kRightEncoderAPin);
  const bool encoderB = digitalRead(kRightEncoderBPin);
  portENTER_CRITICAL_ISR(&gEncoderMux);
  gRightEncoderCount = encoderStep(gRightEncoderCount, encoderA == encoderB);
  portEXIT_CRITICAL_ISR(&gEncoderMux);
}

void updateController(uint32_t nowMs)
{
  const uint32_t elapsedMs = nowMs - gLastControlMs;
  if (elapsedMs < kControlIntervalMs)
  {
    return;
  }

  gLastControlMs = nowMs;
  const float elapsedSeconds = elapsedMs / 1000.0f;
  const EncoderCounts counts = readEncoderCounts();
  gLeftMeasuredSpeed =
      encoderDelta(counts.left, gPreviousLeftEncoderCount) / elapsedSeconds;
  gRightMeasuredSpeed =
      encoderDelta(counts.right, gPreviousRightEncoderCount) / elapsedSeconds;
  gPreviousLeftEncoderCount = counts.left;
  gPreviousRightEncoderCount = counts.right;

  const float maximumTargetChange =
      gTargetSlewRateCountsPerSecondSquared * elapsedSeconds;
  gLeftTargetSpeed =
      moveToward(gLeftTargetSpeed, gLeftRequestedSpeed, maximumTargetChange);
  gRightTargetSpeed =
      moveToward(gRightTargetSpeed, gRightRequestedSpeed, maximumTargetChange);

  gLeftControllerOutput = static_cast<int16_t>(gLeftController.update(
      gLeftTargetSpeed, gLeftMeasuredSpeed, elapsedSeconds));
  gRightControllerOutput = static_cast<int16_t>(gRightController.update(
      gRightTargetSpeed, gRightMeasuredSpeed, elapsedSeconds));

  writeMotorPwm(kLeftRpwmPin, kLeftLpwmPin,
                gLeftControllerOutput * kLeftMotorPolarity);
  writeMotorPwm(kRightRpwmPin, kRightLpwmPin,
                gRightControllerOutput * kRightMotorPolarity);
}

} // namespace

namespace RobotDrive
{

void begin()
{
  pinMode(kDriverEnablePin, OUTPUT);
  digitalWrite(kDriverEnablePin, LOW);

  ledcAttach(kLeftRpwmPin, kPwmFrequencyHz, kPwmResolutionBits);
  ledcAttach(kLeftLpwmPin, kPwmFrequencyHz, kPwmResolutionBits);
  ledcAttach(kRightRpwmPin, kPwmFrequencyHz, kPwmResolutionBits);
  ledcAttach(kRightLpwmPin, kPwmFrequencyHz, kPwmResolutionBits);
  stop();

  pinMode(kLeftEncoderAPin, INPUT);
  pinMode(kLeftEncoderBPin, INPUT);
  pinMode(kRightEncoderAPin, INPUT);
  pinMode(kRightEncoderBPin, INPUT);
  attachInterrupt(digitalPinToInterrupt(kLeftEncoderAPin),
                  onLeftEncoderAChange, CHANGE);
  attachInterrupt(digitalPinToInterrupt(kRightEncoderAPin),
                  onRightEncoderAChange, CHANGE);

  const EncoderCounts initialCounts = readEncoderCounts();
  gPreviousLeftEncoderCount = initialCounts.left;
  gPreviousRightEncoderCount = initialCounts.right;
  gLastControlMs = millis();

  digitalWrite(kDriverEnablePin, HIGH);
}

void commandWheelSpeeds(float leftCountsPerSecond,
                        float rightCountsPerSecond, uint32_t timeoutMs,
                        uint32_t rampDurationMs)
{
  gLeftRequestedSpeed = leftCountsPerSecond;
  gRightRequestedSpeed = rightCountsPerSecond;
  gMotionCommandActive =
      leftCountsPerSecond != 0.0f || rightCountsPerSecond != 0.0f;
  gLastMotionCommandMs = millis();
  gActiveCommandTimeoutMs = timeoutMs;
  gActiveRampDurationMs = rampDurationMs;

  const float largestTarget =
      fmaxf(fabsf(leftCountsPerSecond), fabsf(rightCountsPerSecond));
  if (rampDurationMs == 0)
  {
    gTargetSlewRateCountsPerSecondSquared = largestTarget;
    gLeftTargetSpeed = leftCountsPerSecond;
    gRightTargetSpeed = rightCountsPerSecond;
    gLeftController.reset();
    gRightController.reset();
  }
  else
  {
    gTargetSlewRateCountsPerSecondSquared =
        largestTarget / (rampDurationMs / 1000.0f);
  }
}
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

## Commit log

2026-09-02 Created better planning and agentic coding framework
2026-09-05 Implement encoder-feedback wheel PID control
2026-09-07 Improve encoder output and serial safety; record hardware and geometry updates
2026-09-07 Accept wheel radian commands in ROS firmware and document Pi integration
2026-09-07 Track simulation SLAM implementation and pending runtime checks
2026-09-08 Fix encoder rollover and record integration audit
    [encoder_count_math_test.cpp, robot_drive.cpp]
2026-09-08 Consolidate ROS package and prepare portfolio documentation
    [controllers.yaml, controllers_hardware.yaml, dimensions.xacro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]
2026-09-08 Add robot STEP and STL CAD files
    [Lidar_Holder.stl, PILLAR.stl, autonomous_SLAM_robot_cad.step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]
2026-09-08 Document initial simulated LiDAR SLAM visualization
2026-09-08 Compact simulation room and record successful WSL mapping
    [test_room.sdf]
2026-09-09 Increase simulation navigation speed and lidar update rate
    [controllers.yaml, simulation_parameters.xacro]
2026-09-09 Implement simulation frontier exploration with guarded Nav2 goals and map saving
    [exploration_occluded.sdf]
